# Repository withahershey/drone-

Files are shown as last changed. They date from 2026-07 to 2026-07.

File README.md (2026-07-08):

# Hand-Controlled Drone

A fully custom quadcopter built from raw components — no pre-made flight controller, no off-the-shelf RC transmitter. The drone is stabilized by a self-written PID control loop running on an ESP32, and flown by tilting your hand: a second ESP32 + IMU worn on a glove/wrist strap reads your hand's orientation and sends it wirelessly to the drone in real time.
Built for [Hack Club Outpost](https://outpost.hackclub.com/).
- [Lapse](https://lapse.hackclub.com/user/@withahershey2010)
- [Stardance](https://stardance.hackclub.com/projects/30646)
  


## How it works

- A **hand controller** (ESP32 + MPU6050 + nRF24L01) reads your hand's tilt (roll/pitch) and wrist twist (yaw rate), plus throttle from a potentiometer and an arm/disarm button, and transmits it over a 2.4GHz radio link.
- The **drone** (ESP32 + MPU6050 + nRF24L01 + 4-in-1 ESC) receives that packet, reads its own current attitude from its onboard IMU, runs a PID loop comparing the two, and mixes the correction into 4 individual motor speeds.
- A **failsafe** cuts the motors automatically if the radio signal is lost for more than 300ms.

## Features

- Fully custom PID stabilization — no Betaflight/existing flight controller firmware
- Custom wireless control protocol over nRF24L01+PA+LNA (long-range variant)
- Hand-gesture flight control instead of a standard RC transmitter
- Signal-loss failsafe
- Pendulum-style frame design: flight electronics isolated from motor vibration on damped standoffs, battery mounted low for passive self-leveling stability

## Hardware

| | |
|---|---|
| MCU | ESP32-WROOM-32 (x2 — one per drone, one for the hand controller) |
| IMU | MPU6050 (x2) |
| Radio | nRF24L01+PA+LNA (x2) |
| Motors | 2205 2300KV brushless (x4) |
| ESC | 30A 4-in-1, BLHeli_S |
| Battery | 4S 1500mAh LiPo |
| Frame | Custom-designed two-tier stacked frame, 3D printed |

Full bill of materials with part links: [`docs/drone_bom.csv`](docs/drone_bom.csv)

## Repository structure

```
├── firmware/
│   ├── drone_flight_controller/
│   │   └── drone_flight_controller.ino   # Runs on the drone's ESP32
│   └── hand_controller/
│       └── hand_controller.ino           # Runs on the glove/handheld ESP32
├── hardware/
│   ├── schematics/                       # KiCad schematics (drone + glove)
│   └── cad/                              # Frame CAD files
├── docs/
│   └── drone_bom.csv                     # Full bill of materials
└── README.md
```

## Firmware

Both sketches are written for the Arduino IDE (ESP32 board package).

**Libraries required:**
- [RF24](https://github.com/nRF24/RF24) by TMRh20
- [MPU6050_light](https://github.com/rfetick/MPU6050_light) by rfetick
- [ESP32Servo](https://github.com/madhephaestus/ESP32Servo) by Kevin Harrington (drone side only)

**Pin assignments** are defined as `#define`s at the top of each `.ino` file — update them to match your own wiring if it differs from the schematics in `hardware/schematics/`.

### Hand controller (`firmware/hand_controller/`)
Reads hand tilt (roll/pitch) and wrist twist rate (yaw) from the MPU6050, reads throttle from a potentiometer, and toggles an armed/disarmed state on each button press. Packages all of it into a struct and transmits it over the radio at ~50Hz.

### Drone flight controller (`firmware/drone_flight_controller/`)
Receives the control packet, reads its own attitude from its onboard IMU, and runs independent PID loops for roll, pitch, and yaw rate. Outputs are mixed using standard X-quad motor mixing and written to the ESC as PWM (1000–2000µs). Motors are held at minimum signal whenever the drone is disarmed or the signal has timed out.

## Building it

1. Solder the ESP32, MPU6050, and nRF24L01 onto perfboard per the schematics in `hardware/schematics/`
2. Mount the electronics stack and ESC/PDB on the 3D-printed frame using vibration-damping standoffs
3. Flash `hand_controller.ino` to the hand controller's ESP32 and `drone_flight_controller.ino` to the drone's ESP32
4. **Remove propellers** and bench-test: verify the IMU calibrates, the radio link connects, and each motor spins the correct direction when armed
5. Tune the PID gains at the top of `drone_flight_controller.ino`, starting with P only, then adding D, then I if needed
6. Only attach propellers once motor response and PID behavior look correct on the bench

## Safety notes

- Always test with propellers **off** first
- Keep hands and body clear of the propeller plane during any powered test
- The arm/disarm button and failsafe are there for a reason — don't bypass them
- LiPo batteries can be dangerous if punctured, overcharged, or short-circuited — always use a balance charger and never leave a charging battery unattended

## Status

Work in progress, built for the Hack Club Outpost hardware program (2026).

## Pictures





## License

MIT

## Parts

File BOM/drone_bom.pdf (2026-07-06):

# Hand-Controlled Drone — Bill of Materials

## Tools

Item | Spec | Qty needed | Buy | Est. Price | Link
Soldering iron kit (all-in-one) | 60W adjustable temp, includes digital multimeter, wire stripper/cutter , solder wire, desoldering pump, tweezers, stand | 1 | 1 | ~$27 | Soldering Iron Kit w/ Digital Multimeter, Wire Stripper, Solder (https://www.amazon.com/Soldering-Multimeter-Desoldering-Stripper-Tweezers/dp/B08GWN1ZCZ)

This single kit covers the soldering iron, solder, wire stripper, and multimeter all at once — no need to buy those separately.

## Flight Electronics (center stack)

Item | Spec | Qty needed | Buy | Est. Price | Link
ESP32 Dev Board | ESP-WROO M-32 | 2 (1 drone, 1 hand controller) | 2-pack | ~$12 | HiLetgo 2pcs ESP32 (https://www.amazon.com/HiLetgo-ESP-WROOM-32-Development-Microcontroller-Integrated/dp/B0718T232Z)
IMU | MPU6050 (GY-521) | 2 (1 drone, 1 glove) | 2-pack | ~$8 | Ximimark 2pcs MPU-6050 (https://www.amazon.com/Ximimark-MPU-6050-Accelerometer-Gyroscope-Converter/dp/B07MMZ37PT)
Radio | nRF24L01+P A+LNA (SMA antenna) | 2 (1 pair) | 2-pack | ~$15 | HiLetgo 2pcs nRF24L01+P A+LNA (https://www.amazon.com/HiLetgo%C2%AE-NRF24L01-Wireless-Transceiver-Compatible/dp/B00WG9HO6Q)

## Propulsion

Item | Spec | Qty needed | Buy | Est. Price | Link
Brushless motors | 2205 2300KV, 2×CW + 2×CCW | 4 | 1 set of 4 | ~$32 | Readytosky RS2205 2300KV (4pcs) (https://www.amazon.com/Readytosky-RS2205-2300KV-Brushless-Multicopter/dp/B088NGCZ64)
4-in-1 ESC | BL_S 30x30 | 1 board (drives all 4 motors) | 1 | ~$32 | AERO SELFIE 45A 4in1 ESC (https://www.amazon.com/AERO-SELFIE-Freestyle-Supports-Lightweight/dp/B0DQXPW3H4)
Propellers | 5045 tri-blade, 2×CW + 2×CCW | 4 (+spares) | 2 packs (buy spares — you will crash) | ~$16 for 2 packs | Gemfan 5045 propellers (2 pair) (https://www.amazon.com/Propeller-Professional-3-Blades-FreyBlue-Propellers/dp/B07FTLY5FJ)

## Power

Item | Spec | Qty needed | Buy | Est. Price | Link
LiPo battery | 4S 1500mAh, 100C, XT60 | 2 (fly one, charge the other) | 2-pack | ~$35 | CNHL 1500mAh 4S 100C (2 pack) (https://www.amazon.com/CNHL-Quadcopter-Helicopter-Airplane-Multi-Motor/dp/B07V1TYR3P)
Balance charger | 1S–6S, 80W/6A | 1 | 1 | ~$25 | 80W 6A Balance Charger/Disc harger (https://www.amazon.com/Battery-Charger-Balance-Discharger-Batteries/dp/B0F5HPV5BR)
XT60 connectors | male/female pairs, for wiring battery leads/PDB | ~5 pairs | 20-pair pack (spares) | ~$10 | XT60 Connectors, 20 pairs w/ heat shrink (https://www.amazon.com/MADCATZ-Connectors-High-Temp-Gold-Plated-Battery/dp/B0F8VKKGMN)
Low-voltage alarm | plug-in LiPo cell checker/buzz er (no coding needed) | 1 | 4-pack | ~$9 | Readytosky LiPo Battery Checker/Alar m (4pcs) (https://www.amazon.com/Readytosky-Battery-Monitor-Voltage-Indicator/dp/B01FHIMU0M)

Item | Spec | Qty needed | Buy | Est. Price | Link
PDB | 3S-10S Input, 5V/12V Output | 1 | 1 | ~$24 | AERO SELFIE 4IN1 PDB (https://www.amazon.com/AERO-SELFIE-Distribution-Brushless-30-5x30-5mm/dp/B0F9WJBGFM)
Buck Converter | 3v to 5v | 1 | 2 pack | ~$5 | Buck Converter Mini 5V 3V (https://www.amazon.com/MTDELE-MP1584EN-DC-DC-Adjustable-Module/dp/B0DC3N7PMY)

## Build / Assembly Hardware

Item | Spec | Qty needed | Buy | Est. Price | Link
Perfboard | for soldering ESP32/MPU 6050/nRF24L 01 in place of a PCB | a few boards | 32-pc assorted kit | ~$9 | ELEGOO 32pc Prototype Board Kit (https://www.amazon.com/ELEGOO-Prototype-Soldering-Compatible-Arduino/dp/B072Z7Y19F)
Nylon standoffs | M3, assorted lengths, for stacking plates | as needed | 320-pc kit | ~$10 | Litorange 320pc M3 Nylon Standoff Kit (https://www.amazon.com/Litorange-320PCS-Standoff-Assorted-Assortment/dp/B07D782FJJ)
Silicone hookup wire | 22AWG, multi-color, for point-to-point wiring | 1 kit | 1 | ~$13 | TUOFENG 22AWG Silicone Wire (6 colors) (https://www.amazon.com/Electric-Flexible-Silicone-different-Electronic/dp/B07G2JWYDW)
Vibration-da mping foam | isolates flight electronics from motor vibration | 1 pack | 12-pc | ~$8 | CSM Vibration Isolation Foam Squares (12pc) (https://www.amazon.com/Controller-Mounting-Squares-Vibration-Isolation/dp/B01N8OFDVP)
Heat shrink tubing | assorted sizes, for wire joints | 1 kit | — | ~$8 | (included w/ some connector kits above, or buy any

Item | Spec | Qty needed | Buy | Est. Price | Link
| | | | | assorted heat-shrink pack)

## Hand Controller (glove/handheld unit)

Reuses the second ESP32 + MPU6050 + nRF24L01 listed above. Mount them on:

- A snug fingerless glove or elastic wrist strap (any sporting-goods or hardware store option works — no special electronics-specific product needed; a wristband is actually easier to mount rigidly than a glove under time pressure)
- Small piece of leftover perfboard + double-sided foam tape to fix the IMU flat against the back of the hand/wrist so its orientation stays consistent

## Frame

Custom two-tier stacked frame with arms — 3D printed (handled separately).

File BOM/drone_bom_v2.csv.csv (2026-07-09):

Category | Item | Spec | Qty Needed | Buy | Est. Price | Link
Tools | Soldering iron kit (all-in-one) | 60W adjustable temp, includes digital multimeter, wire stripper/cutter, solder wire, desoldering pump, tweezers, stand | 1 | 1 | 18 | https://www.amazon.com/gp/product/B0FR4SR9BD
Controller Inputs | Throttle potentiometer | 10K ohm, linear taper, breadboard-friendly with knob | 1 | 10-pack - I HAVE THIS | 0 | https://www.amazon.com/Breadboard-Friendly-Potentiometer-10K-Arduino/dp/B071ZVNFJ8
Controller Inputs | Arm/disarm button | 6mm momentary tactile push button, with jumper leads | 1 | 5-pack - HAVE THIS | 0 | https://www.amazon.com/MakerSpot-Momentary-Extension-Breadboard-Friendly/dp/B01J9KO7DC
Flight Electronics | ESP32 Dev Board | ESP-WROOM-32 | 2 (1 drone, 1 hand controller) | 2-pack | 15 | https://www.amazon.com/HiLetgo-ESP32-DevKitC-ESP32-WROOM-32U-ESP-WROOM-32U-Development/dp/B09KLS2YB3
Flight Electronics | IMU | MPU6050 (GY-521) | 2 (1 drone, 1 glove) | 2-pack | 8 | https://www.amazon.com/Ximimark-MPU-6050-Accelerometer-Gyroscope-Converter/dp/B07MMZ37PT
Flight Electronics | Radio (BUDGET SWAP) | nRF24L01+ basic (no PA/LNA) -- shorter range than PA/LNA version, fine for short line-of-sight test flights | 2 (1 pair | 2 spares included) | $8 | https://www.amazon.com/HiLetgo-NRF24L01-Wireless-Transceiver-Module/dp/B00LX47OCY
Propulsion | Brushless motors | 2205 2300KV, 2xCW + 2xCCW | 4 | 1 set of 4 | 37 | https://www.amazon.com/Readytosky-RS2205-2300KV-Brushless-Multicopter/dp/B088NGCZ64
Propulsion | 4-in-1 ESC | 30A, BLHeli_S | 1 board (drives all 4 motors) | 1 | 33 | https://www.amazon.com/AERO-SELFIE-Freestyle-Supports-Lightweight/dp/B0DQXPW3H4
Propulsion | PDB | 320A Adapter Module | 1 board | 1 | 25 | www.amazon.com/AERO-SELFIE-Distribution-Brushless-30-5x30-5mm/dp/B0F9WJBGFM
Propulsion | Propellers (BUDGET SWAP) | 5045 tri-blade, 2xCW + 2xCCW -- buying just 1 pack means no spares for crashes | 4 | 1 pack | 9 | https://www.amazon.com/uxcell-Propellers-Quadcopter-Hexacopter-Multirotor/dp/B07Y6JZ3T2
Power | LiPo battery (BUDGET SWAP) | 4S 1500mAh, 100C, XT60 -- single battery means no backup while charging | 1 | 1-pack | 18 | https://www.amazon.com/Ovonic-Battery-1550mAh-Connector-Quadcopter/dp/B08998Z859?th=1
Power | Balance charger | 1S-6S, 80W/6A | 1 | 1 | 34 | https://www.amazon.com/Battery-Balance-Charger-Discharger-Digital/dp/B0F6MP2Q5D
Power | XT60 connectors (BUDGET SWAP) | male/female pairs, for wiring battery leads/PDB | ~5 pairs | 5-pair pack | 9 | https://www.amazon.com/ZHOFONET-Connector-Adapter-Silicone-Battery/dp/B0DCFQPNFS?th=1
Power | Low-voltage alarm | plug-in LiPo cell checker/buzzer (no coding needed) | 1 | 4-pack | 9 | https://www.amazon.com/gp/product/B08YY5ZL93?th=1
Build/Assembly Hardware | Perfboard | for soldering ESP32/MPU6050/nRF24L01 in place of a PCB | a few boards | 32-pc assorted kit | 8 | https://www.amazon.com/gp/product/B0DBZ1BXFZ
Build/Assembly Hardware | Silicone hookup wire (BUDGET SWAP) | 22AWG, red + black, for point-to-point wiring | 1 kit | 2-color 10ft kit | 9 | https://www.amazon.com/DAOKAI-Silicone-Stranded-Electrical-Printer/dp/B09TK155BW
Build/Assembly Hardware | Heat shrink tubing | included with the connector/wire kits above -- no separate purchase needed | -- | -- |  | (bundled with items above)
Hand Controller | Glove or wrist strap | mounting for second ESP32 + MPU6050 + nRF24L01 | 1 | any sporting-goods option | 0 | (no specific product needed)
Frame | Custom two-tier stacked frame with arms | 3D printed (handled separately) | 1 | -- |  | (handled separately)
 |  |  |  | TOTAL | 240
 |  |  |  | out of pocket - with the grant | 60

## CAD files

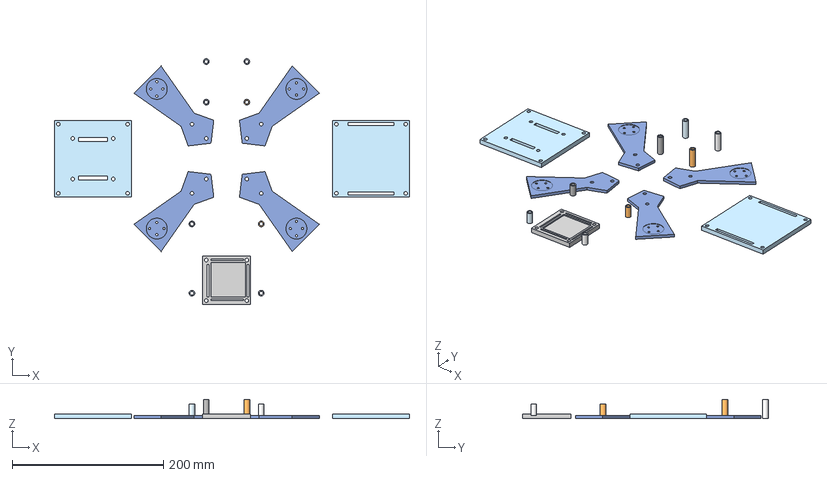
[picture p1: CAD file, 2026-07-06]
CAD & Wiring/Drone 3D print.step
468.9 x 324.5 x 25.4 mm

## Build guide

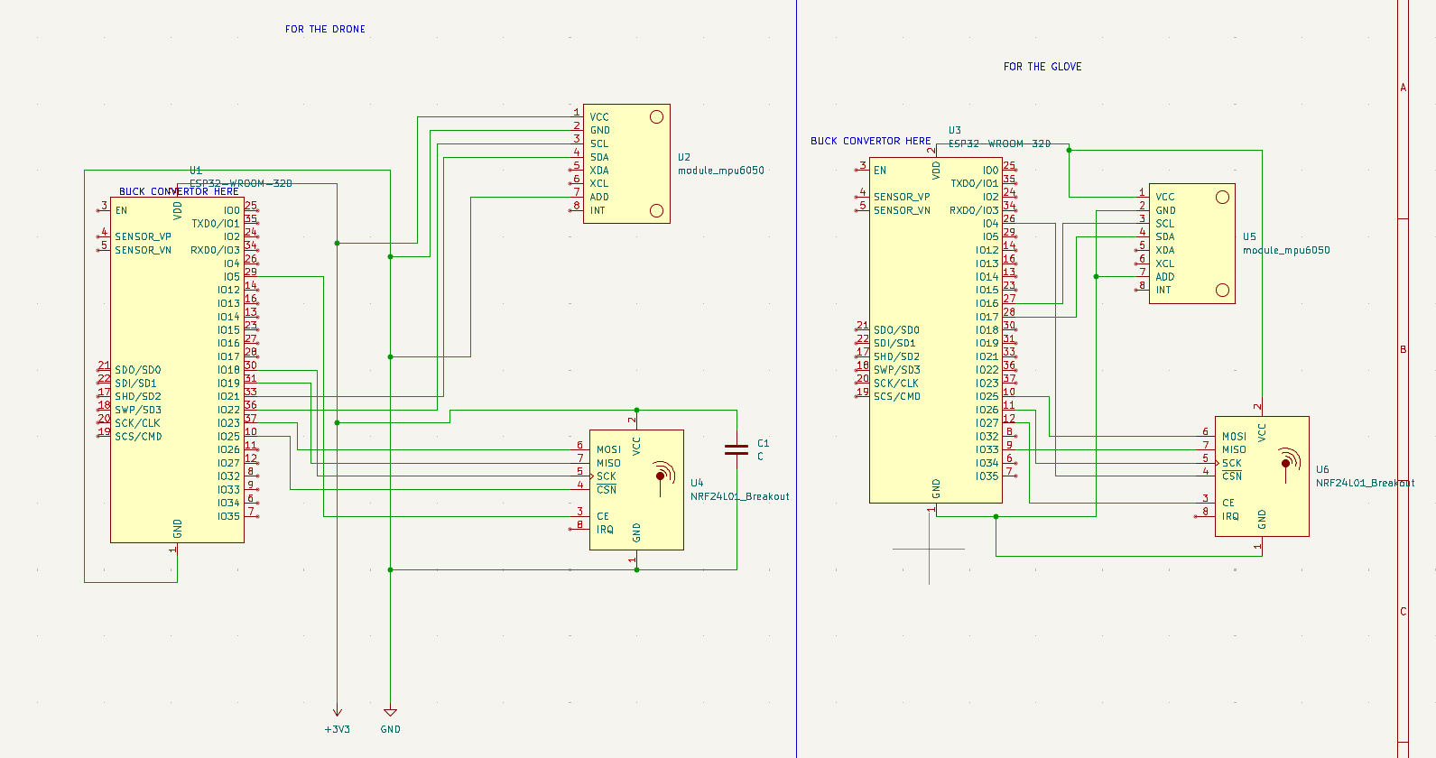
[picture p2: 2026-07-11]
CAD & Wiring/drone L1 wires_updated.png

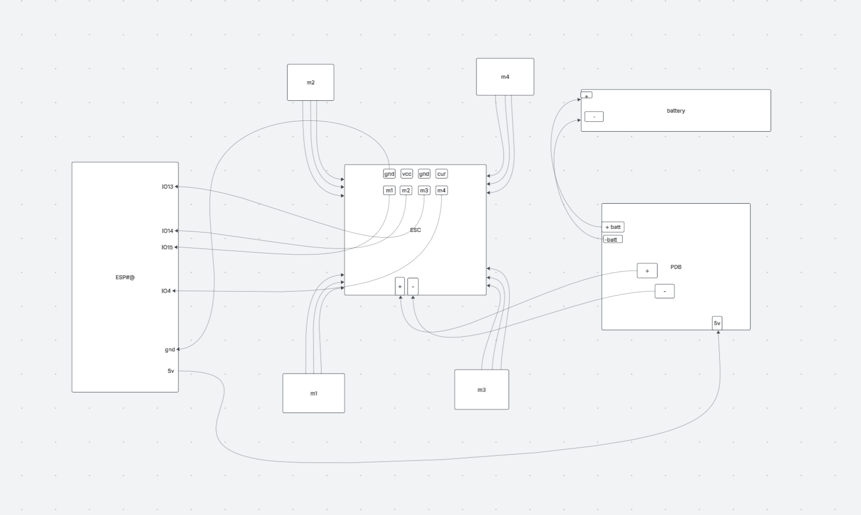
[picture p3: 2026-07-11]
CAD & Wiring/drone L2 wires_updated.png

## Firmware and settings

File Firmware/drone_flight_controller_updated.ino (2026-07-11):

#include <Wire.h>
#include <MPU6050_light.h>
#include <SPI.h>
#include <RF24.h>
#include <ESP32Servo.h>

// ---- I2C (MPU6050) ----
// Uses default ESP32 I2C pins: SDA = GPIO21, SCL = GPIO22

// ---- Radio ----
#define RADIO_CE_PIN   5
#define RADIO_CSN_PIN  25

// ---- ESC signal pins (wire to the 4-in-1 ESC's M1-M4 signal pads) ----
#define M1_PIN 15
#define M2_PIN 14
#define M3_PIN 13
#define M4_PIN 4

MPU6050 mpu(Wire);
RF24 radio(RADIO_CE_PIN, RADIO_CSN_PIN);
Servo escM1, escM2, escM3, escM4;

// This address must be IDENTICAL to the hand controller's.
const byte address[6] = "DRONE";

struct ControlPacket {
  float roll;
  float pitch;
  float yawRate;
  uint8_t throttle;
  bool armed;
};

ControlPacket packet = {0, 0, 0, 0, false};
unsigned long lastPacketTime = 0;
const unsigned long FAILSAFE_TIMEOUT = 300; // ms with no packet before we cut motors

// ---- PID state ----
float rollI = 0, pitchI = 0, yawI = 0;
float rollPrevErr = 0, pitchPrevErr = 0, yawPrevErr = 0;
unsigned long lastPidTime = 0;

// ---- STARTER PID GAINS ----
float rollKp = 2.0,  rollKi = 0.0,  rollKd = 0.5;
float pitchKp = 2.0, pitchKi = 0.0, pitchKd = 0.5;
float yawKp = 1.5,   yawKi = 0.0,   yawKd = 0.0;

const int ESC_MIN = 1000;
const int ESC_MAX = 2000;

void setup() {
  Serial.begin(115200);
  Wire.begin();

  byte status = mpu.begin();
  Serial.print("MPU6050 status: ");
  Serial.println(status);
  while (status != 0) {
    // Halt here if the IMU never connects
  }

  Serial.println("Keep the drone flat and still for calibration...");
  delay(1000);
  mpu.calcOffsets();
  Serial.println("Calibration done.");

  if (!radio.begin()) {
    Serial.println("Radio hardware not responding! Check wiring/power.");
    while (1) {}
  }
  radio.setPALevel(RF24_PA_LOW);
  radio.setDataRate(RF24_250KBPS);
  radio.setChannel(76); // must match the hand controller's channel exactly
  radio.openReadingPipe(0, address);
  radio.startListening();

  escM1.setPeriodHertz(50);
  escM2.setPeriodHertz(50);
  escM3.setPeriodHertz(50);
  escM4.setPeriodHertz(50);
  escM1.attach(M1_PIN, ESC_MIN, ESC_MAX);
  escM2.attach(M2_PIN, ESC_MIN, ESC_MAX);
  escM3.attach(M3_PIN, ESC_MIN, ESC_MAX);
  escM4.attach(M4_PIN, ESC_MIN, ESC_MAX);

  // Send minimum signal so the ESCs arm/initialize correctly.
  escM1.writeMicroseconds(ESC_MIN);
  escM2.writeMicroseconds(ESC_MIN);
  escM3.writeMicroseconds(ESC_MIN);
  escM4.writeMicroseconds(ESC_MIN);
  delay(3000); // give the ESCs time to power up and beep-arm

  lastPidTime = millis();
  Serial.println("Drone flight controller ready. Waiting for armed signal...");
}

void loop() {
  mpu.update();

  // ---- Receive the latest command packet, if one arrived ----
  if (radio.available()) {
    radio.read(&packet, sizeof(packet));
    lastPacketTime = millis();
  }

  // ---- Failsafe: cut motors if we haven't heard from the controller recently ----
  bool signalLost = (millis() - lastPacketTime) > FAILSAFE_TIMEOUT;
  bool motorsAllowed = packet.armed && !signalLost;

  // ---- Read the drone's own current attitude ----
  float currentRoll  = mpu.getAngleX();
  float currentPitch = mpu.getAngleY();
  float currentYawRate = mpu.getGyroZ();

  // ---- PID timing ----
  unsigned long now = millis();
  float dt = (now - lastPidTime) / 1000.0;
  if (dt <= 0) dt = 0.001;
  lastPidTime = now;

  // ---- Roll PID: target = packet.roll (from hand), measured = currentRoll ----
  float rollErr = packet.roll - currentRoll;
  rollI += rollErr * dt;
  rollI = constrain(rollI, -50, 50); // anti-windup clamp
  float rollD = (rollErr - rollPrevErr) / dt;
  rollPrevErr = rollErr;
  float rollOut = rollKp * rollErr + rollKi * rollI + rollKd * rollD;

  // ---- Pitch PID ----
  float pitchErr = packet.pitch - currentPitch;
  pitchI += pitchErr * dt;
  pitchI = constrain(pitchI, -50, 50);
  float pitchD = (pitchErr - pitchPrevErr) / dt;
  pitchPrevErr = pitchErr;
  float pitchOut = pitchKp * pitchErr + pitchKi * pitchI + pitchKd * pitchD;

  // ---- Yaw rate PID: target = packet.yawRate, measured = currentYawRate ----
  float yawErr = packet.yawRate - currentYawRate;
  yawI += yawErr * dt;
  yawI = constrain(yawI, -50, 50);
  float yawD = (yawErr - yawPrevErr) / dt;
  yawPrevErr = yawErr;
  float yawOut = yawKp * yawErr + yawKi * yawI + yawKd * yawD;

  // ---- Convert 0-255 throttle to a base ESC pulse width ----
  int baseThrottle = map(packet.throttle, 0, 255, ESC_MIN, ESC_MAX);

  // ---- Standard X-quad motor mixing ----
  // If the drone tips the WRONG way when you tilt it by hand during bench
  // testing, flip the sign on that axis here rather than rewiring anything.
  int m1 = baseThrottle + pitchOut + rollOut - yawOut; // front-left  CCW
  int m2 = baseThrottle + pitchOut - rollOut + yawOut; // front-right CW
  int m3 = baseThrottle - pitchOut + rollOut + yawOut; // rear-left   CW
  int m4 = baseThrottle - pitchOut - rollOut - yawOut; // rear-right  CCW

  m1 = constrain(m1, ESC_MIN, ESC_MAX);
  m2 = constrain(m2, ESC_MIN, ESC_MAX);
  m3 = constrain(m3, ESC_MIN, ESC_MAX);
  m4 = constrain(m4, ESC_MIN, ESC_MAX);

  if (motorsAllowed) {
    escM1.writeMicroseconds(m1);
    escM2.writeMicroseconds(m2);
    escM3.writeMicroseconds(m3);
    escM4.writeMicroseconds(m4);
  } else {
    escM1.writeMicroseconds(ESC_MIN);
    escM2.writeMicroseconds(ESC_MIN);
    escM3.writeMicroseconds(ESC_MIN);
    escM4.writeMicroseconds(ESC_MIN);
    // Reset integrators so they don't wind up while sitting disarmed.
    rollI = 0; pitchI = 0; yawI = 0;
  }

  delay(4); // ~250Hz control loop -- adjust based on real-world performance
}

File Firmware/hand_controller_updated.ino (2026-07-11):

#include <Wire.h>
#include <MPU6050_light.h>
#include <SPI.h>
#include <RF24.h>

// ---- I2C (MPU6050) ----
#define I2C_SDA_PIN 17
#define I2C_SCL_PIN 16

// ---- Radio (nRF24L01+PA+LNA) ----
#define RADIO_CE_PIN    27
#define RADIO_CSN_PIN   4
#define RADIO_MOSI_PIN  25
#define RADIO_MISO_PIN  33
#define RADIO_SCK_PIN   26

// ---- Throttle potentiometer (NOT in original BOM -- add a cheap 10k pot) ----
#define THROTTLE_PIN 34   // analog input, ESP32 ADC1 channel

// ---- Arm/disarm push button (NOT in original BOM -- add a cheap button) ----
#define ARM_BUTTON_PIN 32

MPU6050 mpu(Wire);
SPIClass radioSPI(VSPI);
RF24 radio(RADIO_CE_PIN, RADIO_CSN_PIN);

// This address must be IDENTICAL on both the hand controller and the drone.
const byte address[6] = "DRONE";

struct ControlPacket {
  float roll;       // hand tilt left/right, degrees, target attitude
  float pitch;      // hand tilt forward/back, degrees, target attitude
  float yawRate;     // wrist twist rate, deg/sec, target yaw rate
  uint8_t throttle; // 0-255
  bool armed;       // true = motors allowed to spin on the drone
};

ControlPacket packet;

bool armed = false;
bool lastButtonState = HIGH;
unsigned long lastDebounce = 0;

void setup() {
  Serial.begin(115200);
  Wire.begin(I2C_SDA_PIN, I2C_SCL_PIN);

  pinMode(ARM_BUTTON_PIN, INPUT_PULLUP);

  byte status = mpu.begin();
  Serial.print("MPU6050 status: ");
  Serial.println(status);
  while (status != 0) {
    // Halt here if the IMU never connects -- check wiring before continuing.
  }

  Serial.println("Keep the controller flat and still for calibration...");
  delay(1000);
  mpu.calcOffsets(); // calibrates gyro + accel offsets
  Serial.println("Calibration done.");

  radioSPI.begin(RADIO_SCK_PIN, RADIO_MISO_PIN, RADIO_MOSI_PIN, RADIO_CSN_PIN);
  if (!radio.begin(&radioSPI)) {
    Serial.println("Radio hardware not responding! Check wiring/power.");
    while (1) {}
  }
  radio.setPALevel(RF24_PA_LOW); 
  radio.setDataRate(RF24_250KBPS);
  radio.setChannel(76); 
  radio.openWritingPipe(address);
  radio.stopListening();

  Serial.println("Hand controller ready. Starts DISARMED.");
}

void loop() {
  mpu.update();

  // Hand tilt becomes the target roll/pitch angle, clamped to a safe range.
  packet.roll  = constrain(mpu.getAngleX(), -45, 45);
  packet.pitch = constrain(mpu.getAngleY(), -45, 45);
  packet.yawRate = constrain(mpu.getGyroZ(), -100, 100);

  // Throttle: map potentiometer 0-4095 (ESP32 ADC range) to 0-255.
  int raw = analogRead(THROTTLE_PIN);
  packet.throttle = map(raw, 0, 4095, 0, 255);

  // Arm/disarm toggles on each button press (debounced).
  bool buttonState = digitalRead(ARM_BUTTON_PIN);
  if (buttonState == LOW && lastButtonState == HIGH && millis() - lastDebounce > 250) {
    armed = !armed;
    lastDebounce = millis();
    Serial.println(armed ? "ARMED" : "DISARMED");
  }
  lastButtonState = buttonState;
  packet.armed = armed;

  radio.write(&packet, sizeof(packet));

  delay(20);
}

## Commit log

2026-07-08 7/8 3:11
    [drone_bom - drone_bom.csv.csv]
2026-07-09 7/9 7:55pm
    [drone_bom - drone_bom.csv.csv, drone_bom_v2.csv.csv]
